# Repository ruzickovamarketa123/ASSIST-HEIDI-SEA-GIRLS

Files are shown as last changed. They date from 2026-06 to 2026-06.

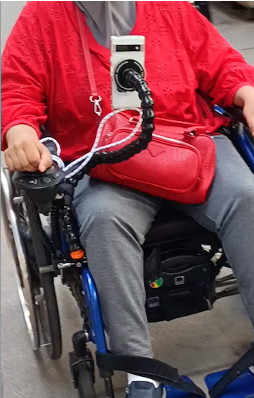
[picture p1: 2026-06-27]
docs/photos/prototype.jpg

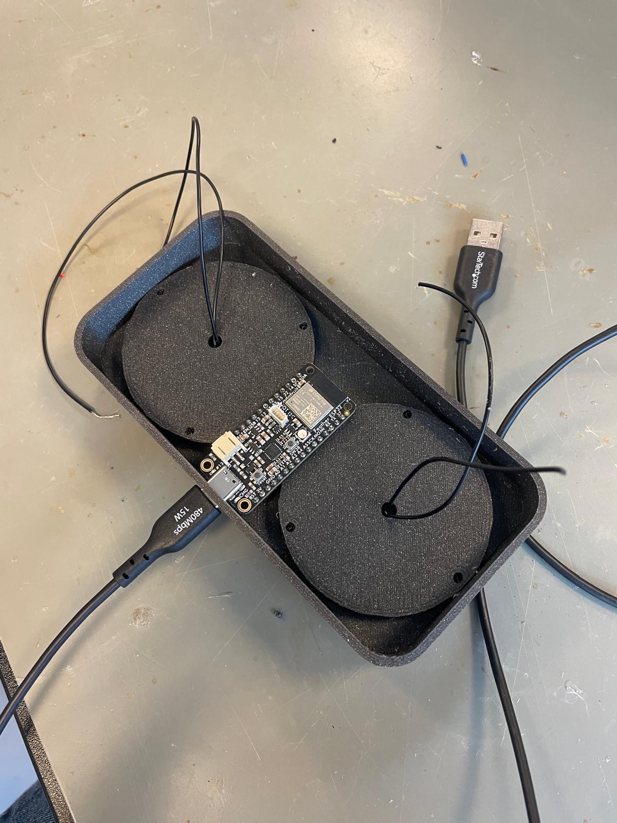
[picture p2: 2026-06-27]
docs/photos/controller2.JPG

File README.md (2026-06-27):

# Marua: Taking Pictures and Videos

> Wheelchair-mounted smartphone stabilizer with Bluetooth remote for hands-free photography and video recording.

**Team:** Seagirls 
**Members:** Natálie Martincová 🇨🇿 · Alina Paschedag 🇩🇪 · Markéta Růžičková 🇨🇿  
**License — Code:** [MIT License](LICENSE)  
**License — Documentation:** [CC BY 4.0](https://creativecommons.org/licenses/by/4.0/)  
**Estimated Total Cost:** ~€90

[Prototype](docs/photos/prototype.jpg) 

---

## Problem

### User Request

Marua is a 30-year-old wheelchair user diagnosed with **myoclonic epilepsy**. A core symptom of her condition is involuntary tremors and twitching of the hands. She wanted to take photos and record videos — including while moving in her wheelchair — without the results being blurry or shaky.

She needed a solution that would:
- Stabilize her smartphone independently of her hand movements
- Be easily attached to and removed from her wheelchair
- Allow her to switch between photo and video mode remotely
- Allow her to trigger the shutter remotely, without touching the phone
- Be usable while the wheelchair is in motion

### Impairment and Remaining Functions

| Aspect | Details |
|---|---|
| Diagnosis | Myoclonic Epilepsy |
| Primary Limitation | Uncontrollable tremors and twitching of the hands |
| Remaining Functions | Can press large buttons with fingers even with limited fine motor control |
| Controller Requirement | Simple push-button controller with large buttons, no fine motor control needed |
| Cognitive Ability | Fully capable; communicates without difficulty |

---

## Solution

The Seagirls team designed and built a **two-part assistive technology solution**:

1. A flexible, wheelchair-mounted **smartphone stabilizer** based on the Loc-Line modular hose system with a magnetic phone adapter, fixed to the wheelchair frame using a screw-tightening clamp
2. A custom **3D-printed Bluetooth remote controller** with two large tactile buttons, powered by an Adafruit Feather V4 microcontroller

### What Can Be Done with the Solution?
- Mount a smartphone securely to the wheelchair at any angle
- Adjust the position and angle of the phone using the flexible Loc-Line arm
- Switch between photo mode and video mode with one button press
- Take a photo or start/stop video recording with the shutter button
- Use the device while stationary or while the wheelchair is moving

### Design Principles

| Design Principle | Implementation |
|---|---|
| Adaptable to any wheelchair | Screw-tightening clamp fits most standard wheelchair frames |
| Compatible with any smartphone | Magnetic adapter works with any phone regardless of brand or size |
| Openable enclosure | 3D-printed remote can be opened to replace or upgrade components |
| Lightweight | Minimal weight to avoid adding strain to the wheelchair setup |
| Stable | Loc-Line arm holds the phone firmly even while moving |
| Good button resistance | Push buttons provide clear tactile feedback, easy to press with tremors |

<!-- ![Solution overview](docs/photos/solution-overview-remote.jpg) -->
<!-- ![Solution overview](docs/photos/solution-overview-holder.jpg) -->

---

## User Documentation

### Components

| Component | Description |
|---|---|
| Loc-Line arm (3/4") | Flexible modular hose, adjustable to any angle |
| Magnetic phone adapter | Quick-attach/detach, compatible with any smartphone |
| Wheelchair clamp | Screw-tightening clamp, fits any standard wheelchair frame |
| Bluetooth remote | 3D-printed openable enclosure, 2 tactile push buttons |
| LiPo battery | 3.7V 800mAh, rechargeable via USB-C |

### Setting Up

1. Attach the Loc-Line arm to the wheelchair frame using the screw-tightening clamp
2. Attach the magnetic adapter to the end of the Loc-Line arm
3. Attach a magnetic sticker to your phone case (or insert it between the phone and case)
4. Attach the smartphone to the magnetic adapter
5. Adjust the arm to the desired position and angle
6. Turn on the Bluetooth remote
7. Pair the remote with the smartphone via Bluetooth
8. Open the camera app on the smartphone

### Controls

| Button | Action | Notes |
|---|---|---|
| Button 1 — Shutter | Take photo / Start–Stop video recording | Main trigger button |
| Button 2 — Mode | Switch between photo and video mode | Toggle function |

[Control layout](docs/photos/controls.jpg) 

---

## Technical Documentation

### Materials, Components and Costs

| Item | Details / Source | Est. Cost |
|---|---|---|
| Loc-Line modular hose (3/4") | Amazon — 5-foot coil | ~€50 |
| Magnetic phone holder adapter + stickers | Amazon DE — LIUCOLI | ~€10 |
| Adafruit Feather V4 | BLE + LiPo charging circuit built-in | ~€20 |
| LiPo Battery 3.7V 800mAh | JST connector, fits Adafruit Feather V4 | ~€7 |
| 3D printed enclosure | Prusa MK4S, PLA filament | ~€2 |
| Push buttons (×2) | Tactile momentary push buttons | ~€1 |
| **TOTAL** | | **~€90** |

### Tools Needed
- 3D printer (Prusa MK4S or similar FDM printer)
- PrusaSlicer (free — [prusaslicer.org](https://www.prusaslicer.org/))
- Visual Studio Code
- Soldering iron and solder
- USB-C cable for programming and charging

### 3D Printing — Remote Enclosure

| Parameter | Value |
|---|---|
| Printer | Prusa MK4S |
| Slicer | PrusaSlicer |
| Material | PLA filament |
| Estimated print time | ~3 hours 30 minutes |
| CAD tool | Onshape |

STL files for printing are also included in the [`design/`](design/) folder of this repository.

### Microcontroller and Electronics

The remote controller is based on the **Adafruit Feather V4**, which includes:
- Built-in Bluetooth Low Energy (BLE) module
- Built-in LiPo battery charging circuit
- USB-C port for charging and programming

Two tactile push buttons are wired to GPIO pins of the microcontroller. The LiPo battery (3.7V, 800mAh) connects directly to the JST connector on the Feather V4. All electronics are housed inside the openable 3D-printed enclosure.

### Firmware

| Parameter | Value |
|---|---|
| Development Environment | Visual Studio Code |
| Language | C++ |
| Protocol | Bluetooth HID (Human Interface Device) |
| Button 1 — Shutter | Triggers photo capture or starts/stops video recording |
| Button 2 — Mode | Toggles between photo and video mode |

Firmware source code is located in the [`code`](code/) folder.

### Assembly Steps

1. 3D print the remote enclosure using the provided CAD/STL files
2. Solder the two push buttons to the GPIO pins of the Adafruit Feather V4
3. Connect the LiPo battery to the JST connector on the Feather V4
4. Flash the firmware using Visual Studio Code via USB-C
5. Place the electronics into the 3D-printed enclosure
6. Secure the buttons with hot glue
7. Assemble the Loc-Line arm to the desired length
8. Attach the magnetic phone adapter to the end of the Loc-Line arm
9. Mount the Loc-Line arm to the wheelchair frame using the screw-tightening clamp
10. Pair the remote with the smartphone via Bluetooth and test all functions

---

## Team

| Name | Role | Skills |
|---|---|---|
| Natálie Martincová 🇨🇿 | Prototyper, Documentation | Python, Mechanics, Anatomy |
| Markéta Růžičková 🇨🇿 | Time Manager, User Researcher, 3D design | Anatomy, SQL, C# |
| Alina Paschedag 🇩🇪 | Communicator, Connectivity | Java, Matlab, Electrotechnics, SQL |

---

## License

| Scope | License |
|---|---|
| Code and design files | [MIT License](LICENSE) |
| Documentation | [Creative Commons Attribution 4.0 International (CC BY 4.0)](https://creativecommons.org/licenses/by/4.0/) |

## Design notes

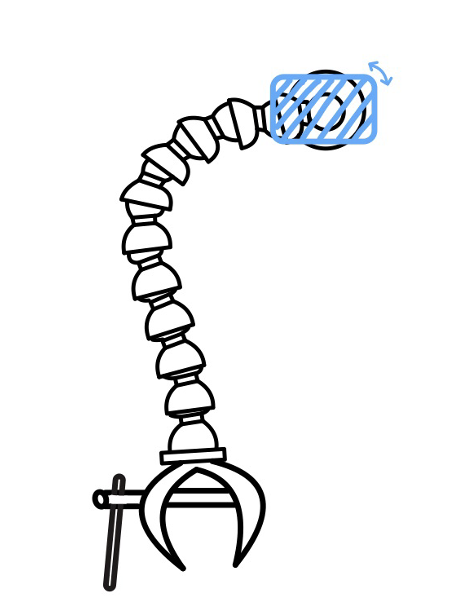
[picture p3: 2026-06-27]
design/holder/holder-design.jpg

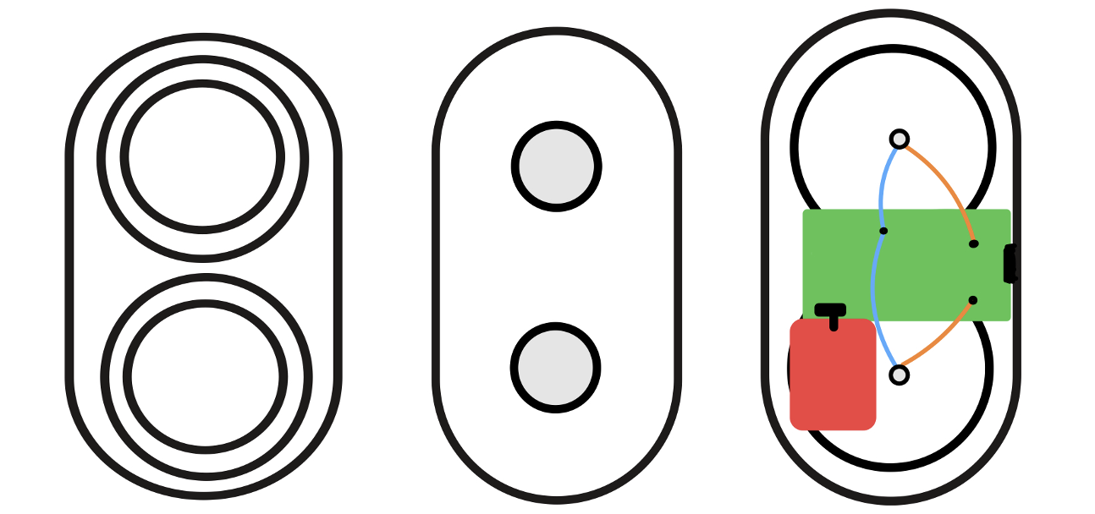
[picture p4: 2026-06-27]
design/remote/remote-design.jpg

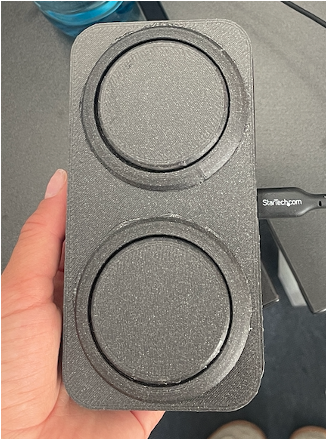
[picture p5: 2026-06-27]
docs/photos/controls.jpg

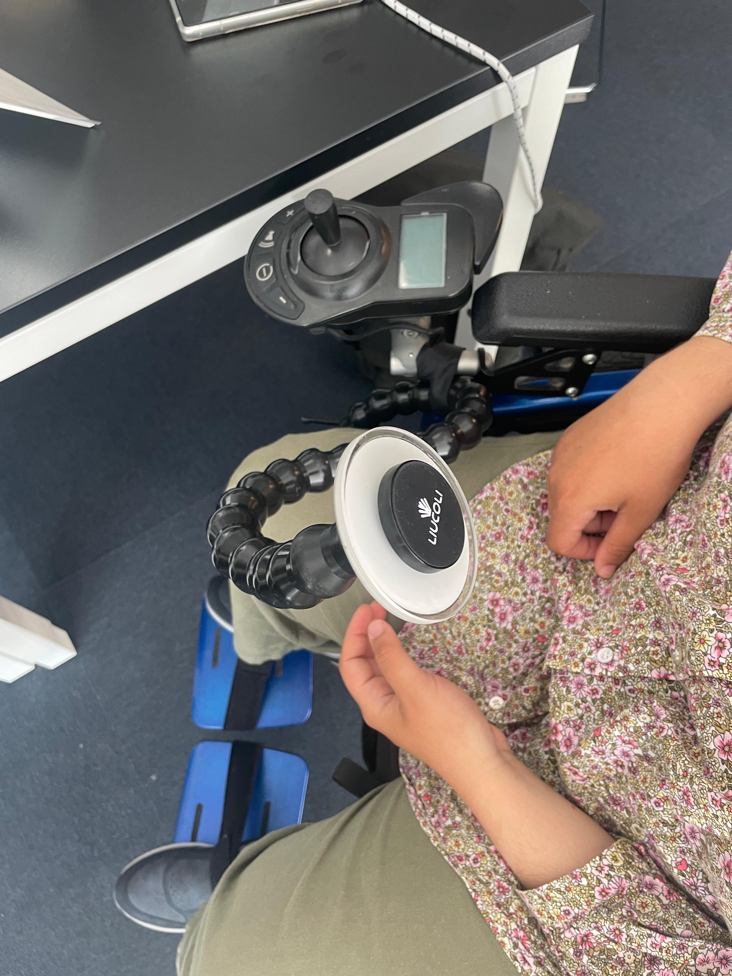
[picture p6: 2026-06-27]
docs/photos/phone_holder.JPG

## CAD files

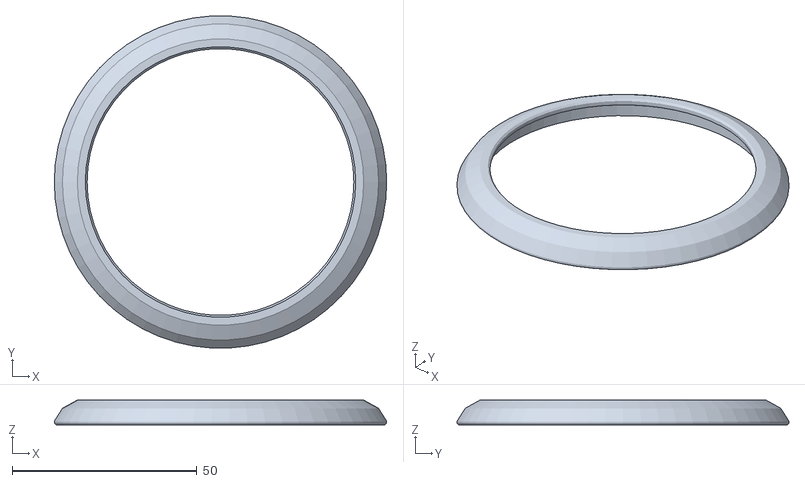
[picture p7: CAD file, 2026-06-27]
design/remote/button-ring.stl
90.0 x 89.9 x 6.75

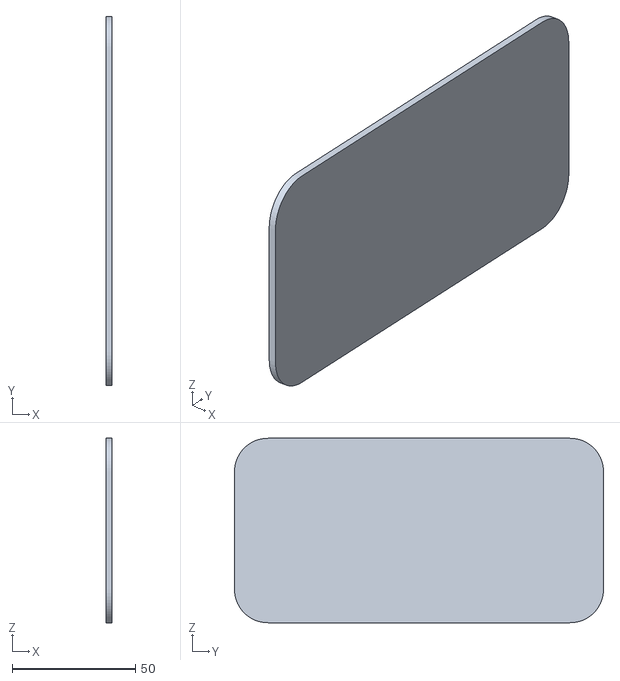
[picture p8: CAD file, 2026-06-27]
design/remote/remote-lid.stl
2.50 x 150.0 x 75.0

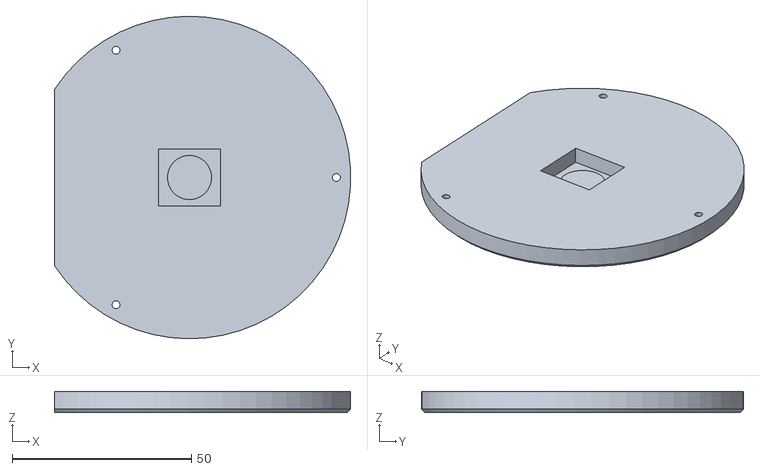
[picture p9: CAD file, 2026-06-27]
design/remote/button-base.stl
82.6 x 90.0 x 6.00

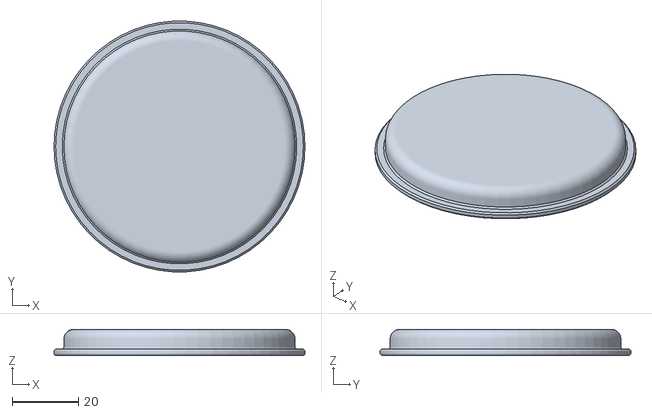
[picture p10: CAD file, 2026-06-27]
design/remote/button-topper.stl
76.0 x 75.9 x 8.00

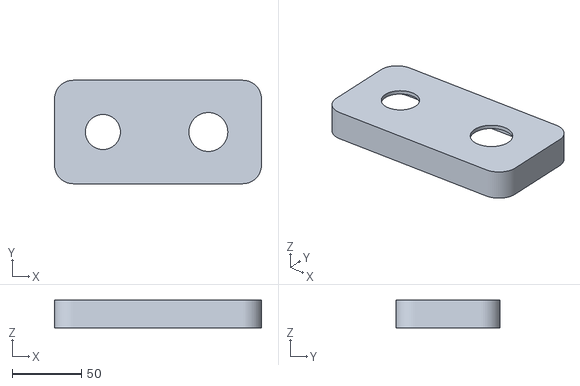
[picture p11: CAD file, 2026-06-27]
design/remote/remote-enclosure.stl
150.0 x 75.0 x 20.0

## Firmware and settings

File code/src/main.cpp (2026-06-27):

#include <Arduino.h>
#include <BleKeyboard.h>
#include <BLEDevice.h>   // Native BLE
#include <BLESecurity.h> // Native BLE Security

BleKeyboard bleKeyboard("Selfie Stick Alina", "Espressif", 100);

const int buttonPin = 33; // Button 1
const int buttonPin2 = 32; // Button 2
int lastButtonState = HIGH;
int lastButtonState2 = HIGH;

void setup()
{
  Serial.begin(115200);
  pinMode(buttonPin, INPUT_PULLUP);
  pinMode(buttonPin2, INPUT_PULLUP);

  Serial.println("Starting Native Bluetooth Keyboard...");

  // Start the keyboard BEFORE setting security
  bleKeyboard.begin();

  // Configure BLE Security
  BLESecurity *pSecurity = new BLESecurity();

  // 1. Force a secure bond
  pSecurity->setAuthenticationMode(ESP_LE_AUTH_REQ_SC_BOND);

  // 2. The Magic Line: "I have no screen and no buttons to type a PIN"
  pSecurity->setCapability(ESP_IO_CAP_NONE);

  // 3. Set standard encryption protocols
  pSecurity->setInitEncryptionKey(ESP_BLE_ENC_KEY_MASK | ESP_BLE_ID_KEY_MASK);
  // --------------------------------
}

void loop()
{
  if (bleKeyboard.isConnected())
  {
    int currentButtonState = digitalRead(buttonPin);

    // Check if Button 1 was just pressed
    if (currentButtonState == LOW && lastButtonState == HIGH)
    {
      Serial.println("Button 1 pressed! Triggering shutter...");
      bleKeyboard.write(KEY_MEDIA_VOLUME_UP);
      delay(200);
    }

    lastButtonState = currentButtonState;

    int currentButtonState2 = digitalRead(buttonPin2);

    // Check if Button 2 was just pressed
    if (currentButtonState2 == LOW && lastButtonState2 == HIGH)
    {
      Serial.println("Button 2 pressed! Triggering shutter...");
      bleKeyboard.write(KEY_MEDIA_MUTE);
      delay(200);
    }

    lastButtonState2 = currentButtonState2;
  }
  delay(10);
} 

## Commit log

2026-04-14 feat: add BLE selfie stick firmware for ESP32-S3-DevKitC-1
    Implement a Bluetooth Low Energy keyboard that triggers a phone
    camera shutter by sending a volume-up key press when the BOOT
    button is pressed.
    - Configure PlatformIO for ESP32-S3-DevKitC-1 (OPI flash, 16 MB)
    - Add ESP32-BLE-Keyboard library dependency
    - Set up secure BLE bonding with no-IO-capability pairing
    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
2026-06-27 Rename Part Studio 1 (1) 2.stl to remote-enclosure.stl
    [remote-enclosure.stl]
2026-06-27 Rename Part Studio 2.stl to remote-lid.stl
    [remote-lid.stl]
